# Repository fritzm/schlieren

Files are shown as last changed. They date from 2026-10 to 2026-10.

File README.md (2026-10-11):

# iPhone schlieren

A portable, single-mirror schlieren apparatus that images with an iPhone and packs into a checked suitcase. It
is built for a vacation week at Deep Creek and afterward will serve as a bench-top lab instrument.

An LED lights a source slit. A spherical mirror a few meters away re-images the slit back at the optical head.
Air density gradients near the mirror bend the returning light past a cutoff (knife edge, wire, or color
filter), and an iPhone behind a telephoto lens records the resulting contrast. The optical head is a pair of
2020-extrusion rails attached to a plywood pivot plate, and is designed to rest on a tabletop or bench.
Thorlabs SM1 optomechanics hold the LEDs, condenser, the slit, and the cutoff, and printed PLA parts handle
everything that doesn't need metal precision. The mirror sits in its own tripod-mounted cell.

## Repository layout

| Path | Contents |
|---|---|
| [`docs/design/`](docs/design/) | Baseline design, as numbered Markdown fragments, one per subsystem. Start with `01-context-and-layout.md`; open areas are flagged **Provisional** and rolled up in `11-open-work.md`. |
| [`docs/schlieren-design.pdf`](docs/schlieren-design.pdf) | The whole design document rendered as one PDF, generated from the fragments. |
| [`bom/bom.csv`](bom/bom.csv) | BOM: one row per allocation, with vendor, SKU, quantity, and procurement or CAD state. |
| [`bom/schlieren-bom.xlsx`](bom/schlieren-bom.xlsx) | The BOM as a workbook with a summary tab, generated from the CSV. |
| [`src/schlieren/parts/`](src/schlieren/parts/) | build123d models of custom parts and part assemblies. Each module's docstring gives its frame and scope. |
| [`src/schlieren/cli/`](src/schlieren/cli/) | Utility scripts for building and viewing parts and generating documents. |
| [`tests/`](tests/) | Checks on dimensions, clearances, interference, optical calculations, and BOM consistency. |
| [`cad/vendor/`](cad/vendor/) | Unmodified manufacturer STEP models of purchased parts. |
| [`docs/reference/`](docs/reference/) | Manufacturer drawings and datasheets. |

This git repository is the source of truth for both the design and the BOM. The PDF and the workbook are
generated views: to change them, edit the fragments or the CSV and rebuild.

## Tooling

- [uv](https://docs.astral.sh/uv/) for management of Python environment and dependencies.
- [build123d](https://build123d.readthedocs.io/) for declarative, parametric geometry, including models for
  3d-printed parts. The Python source is authoritative, and STEP/STL exports are derived files.
- [OCP CAD Viewer](https://github.com/bernhard-42/vscode-ocp-cad-viewer) VS Code extension to display
  assemblies in-editor (`--show`).
- [VTK](https://vtk.org/) for offscreen shaded renders of parts, used as design-document figures (`--figure`).
- [ruff](https://docs.astral.sh/ruff/) for lint and formatting.

## Quick start

```sh
uv sync                                          # set up the environment
uv run run-tests [--full]                        # run the tests in parallel (--full adds the slow ones)
uvx ruff check . && uvx ruff format .            # lint and format

uv run light-source [--show] [--figure]          # light source focus stack-up
uv run slit-head [--show]                        # source-slit flexure head
uv run carriage [--show]                         # cutoff carriage
uv run cassette [--show]                         # cassette blank and clamp bars
uv run rail-shoe [--show] [--figure]             # common rail shoe

uv run build-design-doc [--pdf]                  # docs/design/ -> exports/docs/, docs/schlieren-design.pdf
uv run build-bom-xlsx                            # bom/bom.csv -> bom/schlieren-bom.xlsx
uv run reconcile-bom [workbook.xlsx] [--apply]   # edits made in a workbook -> bom/bom.csv
```

Every part command takes `--help`. The part commands write their STEP/STL files to `exports/`. `--figure`
re-renders the part's design-document figure in `docs/design/figures/`.

Once a design element is accepted, it is propagated to the CAD source and tests, the relevant `docs/design/`
fragment, and `bom/bom.csv`. All of these must agree. In Claude Code, the `/finalize-decision` skill does
this.

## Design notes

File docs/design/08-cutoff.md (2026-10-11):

## 8. Cutoff

The cutoff sits at the returned slit-image plane on the imaging rail. It is a rotating carriage
([§8.1](#81-spigot-and-rotation-interface)–[8.5](#85-spring-seating-and-retraction)) holding interchangeable
64 mm cassettes ([§8.6](#86-common-cassette-standard)–[8.7](#87-cassette-clamp-bars)), which carry the cutoff
element: a knife edge, a fine wire ([§8.8](#88-fine-wire)), or a color filter
([§8.9](#89-color-filter-material)). The carriage model is `src/schlieren/parts/carriage.py`; the cassette
blank and clamp bars are modeled in `src/schlieren/parts/cassette.py`.

<p align="center">
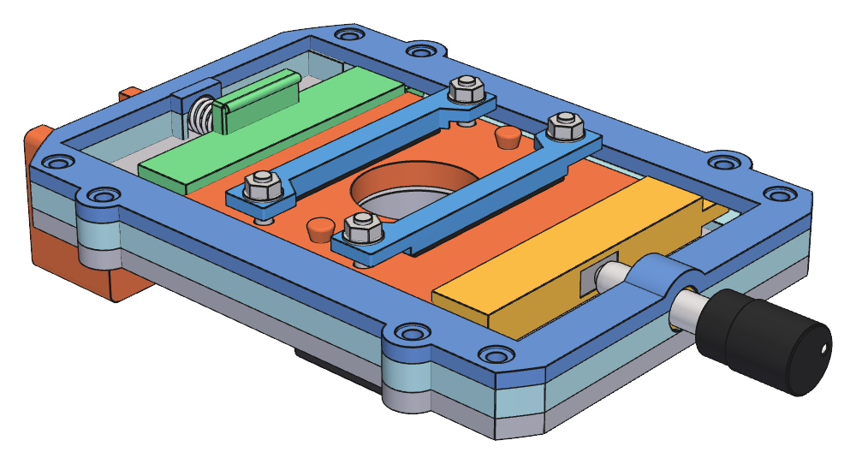
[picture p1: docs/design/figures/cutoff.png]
Cutoff carriage from the mirror side with a cassette seated: base plate, guide frame, keeper plate, driven and spring plungers, FAS100 adjuster, and cassette with clamp bars
  
  <br>
  <em>Fig. 8. Cutoff carriage with a seated cassette: guide frame, keeper plate, driven and spring plungers, and the FAS100 fine adjuster</em>
</p>

### 8.1 Spigot and rotation interface

The carriage mounts in 1 × Thorlabs SM1RC/M through a hollow printed spigot integral with the carriage base
plate, the same interface as the slit-head adapter
([§7.6](07-source-slit.md#76-rotation-mount-and-clearances)):

- Ø30.48 mm spigot (SM1 tube OD nominal), clamped directly by the SM1RC/M split ring (Ø30.7 mm bore, 10.16
  mm thick, M4 locking screw across the split); the spigot end is flush with the ring's rear face;
- Ø24 mm light bore through the spigot, matching the plate aperture;
- Ø34 mm shoulder as the ring's axial stop: the ring seats against it, which places the plate back 12.0 mm in
  front of the ring face. Do not clamp the ring away from the shoulder.

The 12.0 mm ring gap is set by the rail shoe, not the post. At nominal zero the plate reaches about 63.5 mm
below the optical axis, past the shoe top (about 52.4 mm below), so the plate back must clear the shoe end
(15 mm from the post axis): calculated clearance 2.1 mm to the shoe and 10.7 mm to the post body, at every
rotation. The shoulder clears the post top by 5.1 mm.

No SM1 tube, printed split clamp, retaining ring, or printed SM1 thread is used. The
SM1RC/M provides the rotational bearing and lock: when loosened, the carriage rotates on its spigot. Nothing
retains the spigot axially while the ring is loose, so support the carriage when rotating it.

Required carriage rotation:

- at least ±90°
- preferably ±100–120°

Define nominal zero as:

- cutoff line horizontal;
- fine-adjust translation vertical;
- fine adjuster pointing upward.

The cassette-loading side of the carriage faces the mirror, so cassettes are loaded and retracted from the
forward side, away from the telephoto. The spigot, slip ring, and post are therefore aft of the base plate; the
ring's rear face, 22.2 mm behind the plate back, is the rearmost part of the station on the optical axis and
is what the telephoto front must clear.

Fore/aft optical positioning is done by moving the rail shoe.

Rotation envelope: the 2020 rail runs beneath the carriage at every rail position, 72.35 mm below the axis.
The base plate, guide frame, and keeper are trimmed to a 70.35 mm radius about the optical axis (the rail top
less 2 mm clearance). Only the outer plate corners are removed; the plate is otherwise 86 mm wide, widened to
94 mm at the side keeper-screw lugs ([§8.4](#84-cassette-seating)). Calculated from the CAD, the carriage with
its FAS100 rotates clear of the rail over ±150°; only the FAS100 knob reaches the rail, near ±170–180°.
Nothing projects below the plate at nominal zero ([§8.5](#85-spring-seating-and-retraction)). **Provisional:**
clearance to other equipment on the rail near the cutoff station is not yet checked.

### 8.2 Spigot print and fit

The carriage base plate is printed deck down with the spigot up, so the spigot and shoulder need no
supports; the guide frame above the deck is a separate print (the base/frame split exists for this). The three
datum-pin shanks ([§8.4](#84-cassette-seating)) lie outside the shoulder and are flush-cut on the plate back.

**Provisional:** the spigot is printed at the SM1 tube nominal; fit-test it in the SM1RC/M and adjust if
needed.

### 8.3 Fine adjustment

The carriage uses:

- 1 × Thorlabs FAS100, 1/4 in-80 × 1.00 in
- 1 × McMaster 98625A950 brass 1/4 in-80 insert
- 1 × McMaster 2006N292 compression spring

Insert geometry is taken exactly from the McMaster-Carr 98625A950 drawing, not from a generic 1/4 in-80 insert
model. The drawing gives: internal
thread 1/4 in-80; body outside diameter 0.313 in (7.950 mm); overall axial length 0.313 in (7.950 mm);
under-flange/body length 0.298 in (7.569 mm); flange outside diameter 0.352 in (8.941 mm); flange thickness
0.010 in (0.254 mm); specified drill-bit size 0.313 in (7.950 mm); and minimum material thickness 0.298 in
(7.569 mm). The 0.352 in dimension is the flange OD, not the bore or insert-body OD.

The insert bore is nominally 0.313 in (7.950 mm), matching the drawing. The printed bore is a pilot, finished
after printing with a 5/16 in (0.3125 in) drill rather than relying on FDM accuracy; on the slit head this
gave a good press fit ([§7.7](07-source-slit.md#77-fabrication-and-fit)). The 8.5 mm insert support exceeds
the drawing's 0.298 in (7.569 mm) minimum material thickness, with about 3 mm of radial PLA around the insert
body. The spring plunger loads the FAS100 tip, so the screw pushes the insert outboard, toward the knob. The
flange is therefore on the inner (cassette-side) face of the adjuster block, in a flush counterbore 0.2 mm
larger in diameter than the flange, with the body running outboard: the reaction bears the flange against the
block instead of relying on the press fit. The insert is pressed in from the cassette side before the plungers
are installed, with the flange bottoming in its pocket.

FAS100 / insert travel envelope for CAD: the FAS100 uses a 1.000 in (25.4 mm) long 1/4 in-80 adjuster screw.
The 80 TPI pitch gives 0.0125 in (0.3175 mm) axial motion per revolution. Using the insert's 0.313 in overall
axial envelope as a conservative full-engagement allowance leaves approximately 0.687 in (17.45 mm) of
theoretical screw motion. That is a geometric clearance estimate, not a published FAS100 travel
specification. The carriage's working translation is ±5 mm / 10 mm total, leaving useful adjuster margin
before either end stop.

The FAS100 ball tip does not bear directly on printed PLA. The driven plunger carries a small hard bearing
insert made from a nickel-plated rectangular NdFeB magnet:

- Amazon B0DMCY4FN1
- N52 Bar Magnet - 10 mm L × 5 mm W × 2 mm H
- one magnet in the driven plunger

The magnet is used as a hard, wear-resistant plated bearing surface; its magnetic function is incidental. It
sits in a close-fitting printed pocket with its rear face fully supported by PLA, with a small CA or epoxy
tack for retention. The FAS100 ball contacts the broad plated face rather than bare PLA.

### 8.4 Cassette seating

Cassette motion is controlled by opposed plungers:

- fine adjuster on one side;
- spring-loaded plunger opposite;
- three fixed rear datum contacts on the carriage define the cassette optical plane;
- shallow cassette/plunger bevels generate axial seating force against the datum contacts.

The three rear datum contacts are McMaster 97936A109 brass escutcheon pins / decorative finishing nails, used
head-first as small domed sliding contacts. Each pin is approximately 3/8 in long, with a 0.050 in (1.27 mm)
smooth shank and 1/8 in (3.18 mm) domed head.

Mount each pin through a through-hole in the printed carriage with the domed brass head on the cassette side.
The holes are modeled Ø1.75 mm: the measured 0.050 in (1.27 mm) shank, plus the 0.38 mm diametral hole
undersize measured on the first base-plate print (the Ø24 mm aperture printed 0.930 in), plus 0.1 mm fit
clearance. If a shank binds, finish the hole with a #54 (0.055 in) drill. The hole fit only locates the shank; the head sets the datum. Seat the underside of the head firmly against the carriage datum face so datum height is
established mechanically rather than by adhesive thickness. Wick a small amount of CA around the shank from
the back for retention, then flush-cut and dress the projecting shank at the back of the carriage. Keep CA out
from beneath the head/contact surface.

The three pin heads form a broad triangular support pattern around the optical aperture. The cassette rear
face is the sliding datum surface and provides unobstructed swept tracks over the three domed
contacts throughout the fine-adjust travel. The pin coordinates, set in the carriage CAD, keep every datum
contact out of the swept track of the cassette's rear M3 clamp-screw countersinks over the full travel, so
the datum tracks stay on uninterrupted printed rear-face material at every cassette position.

The plunger bodies are constrained to the intended translation axis by ears/tabs riding in slotted guiding
rails. The guide slots prevent unwanted lateral movement or rotation while permitting the required axial
plunger travel.

The plungers need an assembly path into their guides: both longitudinal ends of the guide path are occupied,
by the FAS100 adjuster support on one side and the spring end wall on the other. The guide tracks are
therefore open from the cassette-loading side; the plungers drop into them, and a separate printed keeper
frame closes only the guide-ear regions.

The keeper is a perimeter frame, not a solid lid: the central upper aperture must remain open for cassette
insertion and removal. Its side members span the plunger guide tracks and retain the guide ears against upward
escape while the printed track walls carry the lateral guidance loads. The frame may be locally scalloped or
notched where the FAS100 adjuster axis intersects its envelope, provided the material directly over the swept
guide-ear paths and the load paths to the fasteners remain intact. The keeper's spring-end member also carries
the roof of the end-wall spring cup ([§8.5](#85-spring-seating-and-retraction)).

Keeper retention is mechanical, with eight fasteners per carriage. Each is the existing common McMaster
91292A114 M3 × 0.5 × 12 mm socket-head screw with a McMaster 91828A211 full-height M3 × 0.5 hex nut (5.5 mm
across flats × 2.4 mm high), captive in a hex pocket opening from the plate back. Screw heads and nuts bear
directly on the PLA, without washers; tighten only to a light snug, since the joint needs little clamp and a
firm hex-key torque can crush the bearing face.

- Four end screws, at (±38.5, −53) and (±38.5, +52) mm in the carriage frame (y along the travel, +y toward
  the FAS100). Each sits on solid fill closing its guide track from 1 mm beyond the outermost ear position
  to the plate end. The fill is also the plungers' end stop: 1 mm past full loading retraction for the spring
  plunger and past +5 mm travel for the driven plunger. These positions keep each nut pocket at least 1 mm
  inside the rotation envelope ([§8.1](#81-spigot-and-rotation-interface)).
- Four side screws, at (±42, ±37) mm, beside the middle of each plunger's ear travel. Each sits in a Ø10 mm
  round lug that widens the base, frame, and keeper locally to 94 mm, clipped at the guide-track wall.

The side screws carry the ear wedge reactions (below) into the frame close to where they arise. A first-order
beam estimate, with each keeper side member simply supported between adjacent screws, gives at most about
0.07 mm of upward keeper deflection at the ears at the maximum-compression load (with a PLA modulus of
about 3000 MPa assumed). That is within the 0.25 mm free play between the ears and the keeper; with only the
four end screws it would be about 1.5–2 mm. The keeper
side members are 3.0 mm thick. **Provisional:** if a print shows too much lift, a keeper with 5.0 mm side
members fits the same screws: its counterbores are deeper, so the head seat height is unchanged.

The screw heads sit in an approximately 0.5 mm-deep recess in the keeper, and the captive hex pockets are
approximately 2.5 mm deep. This leaves approximately 1.5 mm of PLA above each nut pocket and gives nearly
full use of the 12 mm screw length, with only slight nominal screw projection beyond the nut. The keeper seats on broad
printed lands, so the fasteners clamp it against the carriage rather than suspending it between isolated
points.

The vertical guide stack is: 4.0 mm carriage back plate; 2.0 mm rise from the plate front to the lower
guide-ear running surface; 3.0 mm plunger guide ears in a 3.4 mm guide channel; and a 3.0 mm keeper frame.

**Provisional:** the guide-stack dimensions, keeper recess and nut-pocket depths, sliding fits, and datum-pin
projection are first-print values, to be tuned from printed fit.

Use a very light film of plastic-safe lubricant on the PLA-on-PLA sliding interfaces, particularly the plunger
ears/tabs in their guide slots and any other plunger sliding faces. The lubricant is McMaster 1418K51
clear silicone grease, NLGI 1. Smooth/dress the printed sliding surfaces first, apply only a trace amount,
cycle the mechanism, and wipe away visible excess so the lubricant acts as a thin boundary film rather than a
grease-packed slide. Keep lubricant away from CA/epoxy/RTV bonding surfaces and apply it only after nearby
adhesive work is complete.

The plunger seating lips and the cassette edge bevels are 27.5° from the cassette plane, with a 1.25 mm
bevel depth.

For keeper-frame sizing, McMaster lists the 2006N292 spring rate as 0.14 lbf/mm. At the 9 mm fiducial
compression this corresponds to approximately 5.6 N of in-plane plunger force; at the 14 mm most-compressed
end of normal travel it is approximately 8.7 N. A frictionless first-order wedge model at 25–30° from the
cassette plane gives approximately 9.7–12.0 N upward reaction per plunger at fiducial and approximately
15.1–18.7 N per plunger at maximum normal compression. These reactions are carried upward through the plunger
ears into the keeper frame; about 20 N per plunger is the working-load scale before safety margin.

**Provisional:** the bevel angle and depth, and the seating-force estimate (which neglects sliding friction),
are pending a cassette insertion, seating, and tilt trial.

### 8.5 Spring seating and retraction

The spring plunger is preloaded by the McMaster 2006N292 compression spring ([§8.3](#83-fine-adjustment)),
acting between the frame's spring end wall and the plunger's outboard face on an axis 7.5 mm above the plate
back. No guide rod, retract handle, or penetration of the end wall is used; a guide rod through the end wall
would project below the axis past the rail top at nominal zero.

Each spring end sits in a printed cup, 3 mm deep, sized to the measured 0.272 in (6.91 mm) coil OD plus 1.0
mm diametral clearance:

- one cup extends inboard from the end wall: its side walls are on the guide frame, and its roof is carried
  by the keeper's spring-end member, so the keeper closes over the spring end when installed;
- one cup extends outboard from the spring plunger;
- both cups are open toward the plate deck, which carries the coil. Their side walls and roofs locate the
  coil ends laterally and against escape toward the cassette-loading side. Both print with legs on the bed
  and the roof bridging the coil, without supports.

The spring's free length is about 4–4.6 times its mean coil diameter, and both ends sit on parallel faces
because the plunger is guided. That is below the roughly 5.3 critical ratio for buckling with fixed ends,
so the cups need only locate the ends rather than guide the full length. The spring itself does not guide
the plunger; the slotted carriage guides constrain plunger translation and rotation.

The spring has a free length of approximately 25.5 mm. The carriage is designed around a 16.5 mm
spring length at the fiducial / mid-travel cassette position, corresponding to approximately 9 mm spring
compression from free length.

Normal supported plunger travel is ±5 mm about the fiducial position, for 10 mm total working travel. The
corresponding spring-length range is approximately:

- 21.5 mm at the least-compressed end of normal travel;
- 16.5 mm at fiducial / mid travel;
- 11.5 mm at the most-compressed end of normal travel.

Loading retraction is a further 6 mm from fiducial (10.5 mm spring length), leaving 4.5 mm between the cups.
Any additional compression capacity is treated as design margin rather than normal commanded travel.
**Provisional:** the solid height of the 2006N292 spring is not verified, so the loading retraction is checked
against the printed cups but not against the spring's own limit.

Retraction for cassette loading uses a thumb tab on the spring plunger's front face at its outboard end:

- 20 mm wide × 3 mm thick × 6 mm tall, centered between the guide ears and outside the cassette footprint;
- the thumb reaches over the cassette and pushes the tab's inner face outboard, at about 9 N at full
  retraction;
- 0.5 mm chamfers on the exposed edges; the spring-facing face is left square;
- a Ø1.6 mm grip bead along the inner top edge, flush with the tab top, prevents finger slip.

The tab is kept low, close to the plane of the guide ears, so that pushing on it does not twist the plunger
and jam the ears.

### 8.6 Common cassette standard

Cassette envelope:

- 64 × 64 × 5 mm PLA
- 24 mm diameter central clear aperture
- identical shallow bevels on all four perimeter edges
- insertable at 0 / 90 / 180 / 270°
- perimeter kept clear enough to use any opposing edge pair
- orientation/polarity indicated by markings rather than a mechanical key.

Cassettes load with the spring plunger retracted 6 mm beyond fiducial
([§8.5](#85-spring-seating-and-retraction)).

Cassette variants, all built on the common blank:

1. single razor knife edge;
2. centered fine-wire or filament dark-field cutoff ([§8.8](#88-fine-wire));
3. striated / multicolor gel filter ([§8.9](#89-color-filter-material));
4. dark-center color filter ([§8.9](#89-color-filter-material)).

<p align="center">
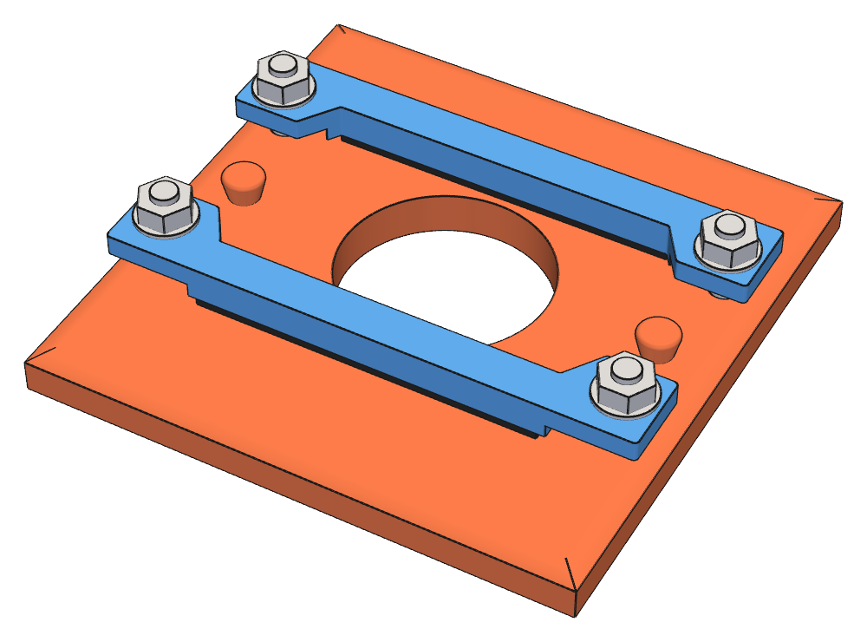
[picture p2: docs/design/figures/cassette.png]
Assembled cassette: 64 mm base with 24 mm aperture, two clamp bars with screws, washers and nuts
  
  <br>
  <em>Fig. 9. Cassette blank with its two clamp bars and hardware</em>
</p>

The standard cassette blank carries one opposed pair of integral filament cleats on the front / non-datum
face, rather than making cleats a special cassette variant: two cleats, one on each side of the 24 mm optical
aperture, at (±25, 0) mm on an aperture centerline, outboard of the razor blades and clamp bars. The cleats
are slightly conical, Ø3.5 mm at the cassette face widening to Ø5 mm toward the top and rising 3 mm, so
filament tension drives fine wire or thread down against the cassette front face. The tops are rounded to
avoid damaging fine wire.
Route a filament in an S path, around opposite sides of the two cleats; the free span then crosses
approximately through the aperture centerline. Small angular error from finite cleat diameter or wrapping is
acceptable because the SM1RC/M rotates the complete tube/cassette assembly. This makes the same universal
cassette blank usable for blade, filter, Photofoil, wire, and thread experiments while keeping the rear datum
face unobstructed.

**Provisional:** cleat geometry is pending a wire-mounting trial.

### 8.7 Cassette clamp bars

These bars and their hardware are the clamping standard for the cassettes
([§8.6](#86-common-cassette-standard)); the slit head uses its own smaller bars
([§7.5](07-source-slit.md#75-blade-clamping)).

Common clamp bars:

- two identical printed rigid PLA bars fit each cassette;
- each bar uses two fasteners, one toward each end, so clamp force is distributed along the element;
- no holes are made through razor blades, filter material, or other optical elements;
- no blade-specific locating pocket or guide is required;
- McMaster 9852N37 adhesive-backed 1/32 in, 60A solid EPDM is applied to the removable clamp-bar face to
  provide compliance and friction;
- the bar bears primarily on the broad flat portion of a razor blade rather than relying on the folded
  spine for its clamp datum;
- the same clamp-bar geometry holds razor knife edges, Roscolux gel/filter material, Photofoil,
  and similar thin sheet cutoff elements.

Clamp-bar fastening is from the cassette rear/datum face toward the optical/front face so no screw ends or
nuts can protrude from the sliding/datum surface. Fasteners are positioned outside the optical-element
footprint where practical; the clamp bar spans and pinches the element against the cassette front face. At
each fastener, use:

flush M3 countersunk flat-head screw → 5 mm cassette body → printed clamp bar → M3 flat washer → ordinary M3
hex nut

The M3 flat-head screw is seated fully flush or very slightly below the rear cassette face and retained in its
countersink with a small CA tack using McMaster 1818A45 / Loctite 4061. The CA serves only to keep the screw
captive and resist rotation while the front-side nut is adjusted; it is not relied upon as the structural
clamp load path. The ordinary M3 nut remains exposed and accessible on the front of the clamp bar. Place the
washer between the nut and printed bar. Do not use prevailing-torque/nyloc nuts or threadlocker here.

#### Cassette clamp-bar hardware

| Component | McMaster part | Specification |
|---|---|---|
| Flat-head screw | [92125A133](https://www.mcmaster.com/92125A133/) | M3 × 0.5 × 14 mm, fully threaded 18-8 stainless, 90° countersunk head; 6 mm head diameter, 1.7 mm head height, 2 mm hex drive |
| Flat washer | [93475A210](https://www.mcmaster.com/93475A210/) | 18-8 stainless, 3.2 mm ID × 7 mm OD × 0.4–0.6 mm thick; DIN 125 / ISO 7089 |
| Ordinary full-height hex nut | [91828A211](https://www.mcmaster.com/91828A211/) | M3 × 0.5, 18-8 stainless, 5.5 mm across flats × 2.4 mm high; DIN 934 (the common split-clamp nut, [§5.3](05-post-support.md#53-common-rail-shoe)) |

The clamp bars are 4 mm printed PLA. The cassette blank has four Ø3.4 mm screw holes at (±27, ±12) mm with
rear-entry 90° countersinks matched to the 92125A133 head (Ø6.2 mm at the face: 6 mm head plus 0.2 mm
diametral allowance), and each bar end provides a washer bearing land at least 7.2 mm across. The screw head
finishes flush with or slightly below the rear/datum face so it cannot contact the carriage datum pins or
interfere with cassette sliding. The fasteners, bars, nuts, cleats, and projecting screw ends are clear of the
24 mm optical aperture and carriage interfaces. The holes and countersinks are features of the universal
cassette blank, not blade-specific geometry.

Because the clamp fasteners do not pass through the optical element, the screw length is not sized from a
blade-thickness stack. The 14 mm length gives full nut engagement and holds razor blades under the 4 mm bars,
with the head seated flush in its countersink. The screws are vertical and the lips act at the cassette edges,
so the screw length does not bear on the lips; the bar ends, which reach the bevel zone, are relieved to clear
them.

### 8.8 Fine wire

The dark-field filament set is enameled copper magnet wire in three readily available AWG sizes. The
nominal diameters below are bare-conductor diameters; enamel makes the finished optical obstruction slightly
larger.

| Wire size | Nominal bare diameter | Approx. metric diameter | Experimental role |
|---|---|---|---|
| 44 AWG magnet wire | 0.0020 in | 0.0508 mm | fine / high-sensitivity filament |
| 34 AWG magnet wire | 0.0063 in | 0.160 mm | intermediate filament, near the expected slit-image width  |
| 30 AWG magnet wire | 0.0100 in | 0.255 mm | coarse filament for stronger gradients / deeper dark field |

Exact finished outside diameter is not critical for the qualitative instrument.

The universal cassette cleat pair described in [§8.6](#86-common-cassette-standard)
is the quick-change mounting for these wires and for dark sewing thread or other fibers. Apply only
modest tension, particularly to 44 AWG wire; the conical cleats seat the filament against the cassette face,
and the S-wrap places the free span approximately on the aperture centerline.

### 8.9 Color-filter material

Filter material is cut from the Roscolux 3 × 6 in Designer Color Selector, which provides more useful
material per color than very small swatches.

For color schlieren:

- use the white Nichia LED;
- lock camera white balance;
- lock exposure.

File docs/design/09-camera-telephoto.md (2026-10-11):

## 9. Camera and telephoto support

The camera and lens are chosen ([§9.1](#91-camera)–[9.2](#92-telephoto)). Their support is a lens cradle and
a phone rest ([§9.4](#94-support-concept)–[9.8](#98-retaining-bands)), with an alignment procedure
([§9.9](#99-lens-alignment)). **Provisional:** the phone rest's retainer and safety catch, the fit allowances
of the printed yokes and of the rod groove, which are still to be tested, and the alignment procedure
([§11](11-open-work.md#11-provisional-areas-and-next-steps)).

### 9.1 Camera

- Apple iPhone 17, base model, in intended protective case
- held in landscape, with the rear cameras toward the mirror and the camera end of the phone toward the
  optical axis
- the Main camera is used, at 1× (or its 2× crop). It is the lower of the two rear apertures with the phone
  in portrait, "rear camera 2" on Apple's drawing (`docs/reference/Apple-iPhone-17.pdf`); the upper aperture
  is the Ultra Wide, used only at 0.5×
- measured camera optical axis approximately 60.6 mm above the lower long edge, in the case
- measured Main camera axis approximately 1.350 in / 34.3 mm from the near short edge, in the case; the case
  shape makes this hard to measure accurately with calipers
- measured case thickness approximately 0.510 in / 12.95 mm (bare phone 7.95 mm); the case corners are rounded
- measured mass 188.7 g bare, with its glass screen protector, and 238.6 g in the case

Manufacturer dimensions of the bare phone, from the drawing:

- both rear cameras are 13.62 mm from the nearer long edge, on a line parallel to it, so the measured axis
  height applies to either aperture
- the Main camera is 31.34 mm from the top short edge, 17.72 mm beyond the Ultra Wide at 13.62 mm
- body 149.61 × 71.45 × 7.95 mm; the camera glass stands 3.45 mm above the back glass

The drawing and the two measurements agree. The cameras are 57.83 mm from the farther long edge of the bare
phone, so the measured 60.6 mm implies a case wall of about 2.8 mm at that edge; the 31.34 mm and the measured
34.3 mm imply about 3.0 mm at the short edge (both calculated).

Initial recording modes:

- 4K/30 for normal work;
- 4K/60 for faster flow phenomena;
- SDR / HDR off as a stable starting point.

### 9.2 Telephoto

- iOgrapher proSnap 7×
- 17 mm mount
- approximately 37.0 mm diameter
- approximately 116.8 mm long
- measured mass approximately 215 g

Measured barrel sections, from the aft end forward:

| Section | Length | Outside diameter |
|---|---|---|
| aft end | 0.565 in / 14.4 mm  | not measured |
| rear cylindrical barrel | 1.300 in / 33.0 mm  | 1.457 in / 37.01 mm |
| long cylindrical barrel | 2.25 in / 57.2 mm | 1.459 in / 37.06 mm |
| focus ring | 0.455 in / 11.6 mm  | not measured |
| front lip | 0.175 in / 4.4 mm | not measured |

Both cylindrical sections are suitable for clamping, giving about 90 mm of clampable barrel from 14.4 mm to
104.5 mm from the aft end. The focus ring must stay clear. The measured sections sum to 4.745 in / 120.5 mm,
about 3.7 mm more than the overall length listed above; the difference is not resolved.

The lens barrel, rather than the phone shell, is the preferred transverse optical datum because accurate lens
centering minimizes vignetting.

### 9.3 Alignment requirements

The returned slit image at the cutoff is the aperture stop for the camera: every ray from the test region
passes through it, then spreads again at the ±1.82° cone angle
([§3.2](01-context-and-layout.md#32-source-cone)). The values below are calculated, and are **provisional**
where they rest on assumed values: a lens front about 42 mm behind the cutoff plane, a 10 mm lit slit image, a
Main-camera pupil of about 3.7 mm (6 mm focal length at f/1.6), and a telephoto clear aperture near 30 mm.

| Quantity | Value |
|---|---|
| Beam cone at the lens front | about 2.7 mm diameter |
| Beam footprint at the lens front | about 2.7 × 12.7 mm |
| Slit image at the phone, reduced 7× by the lens | about 1.4 mm long |
| Frame at 1×, 4K 16:9, through the lens | about 9.9° × 6.1° |
| Mirror in the frame | 3.6° of the 6.1° height  |

The resulting tolerances on the camera and lens as one body:

- centering on the beam: about ±8 mm along the slit direction and ±13 mm across it, before the reduced slit
  image leaves the phone pupil; the lens front aperture allows a similar margin;
- pitch: about ±1.2°, the spare frame height either side of the mirror;
- yaw: about ±3°.

Pointing is therefore the governing adjustment, and centering is forgiving. Image quality still favors
centering well inside the vignetting limit.

### 9.4 Support concept

The phone and the lens threaded onto its case are one rigid body. The lens barrel is its datum
([§9.2](#92-telephoto)): the lens is held at two stations along its barrel, and the phone hangs from its lens
mount. Two separate rail fixtures carry them:

- the lens cradle, specific to the lens, holds the barrel at both stations on four adjusting screws
  ([§9.5](#95-lens-cradle)) and is held down by two retaining bands ([§9.8](#98-retaining-bands));
- the phone rest, specific to the phone, supports the phone's lower edge at one point
  ([§9.6](#96-phone-rest)). A different phone needs only this part redesigned.

<p align="center">
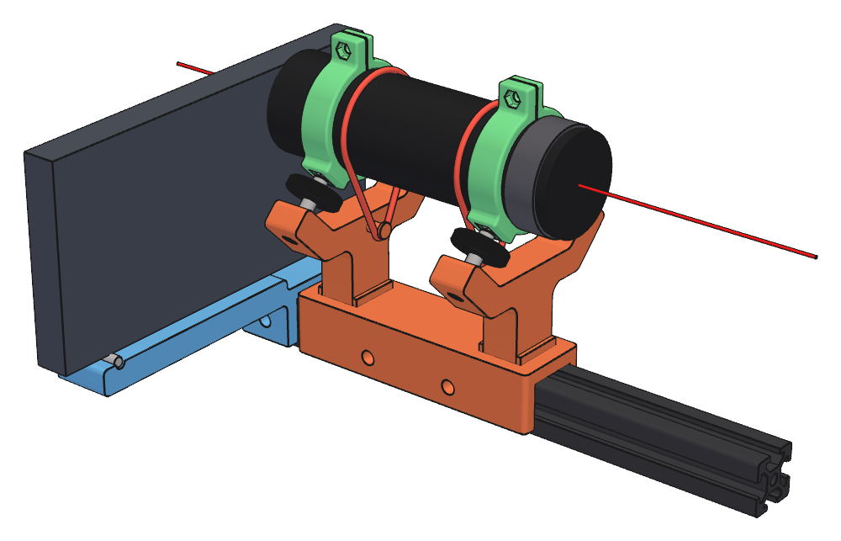
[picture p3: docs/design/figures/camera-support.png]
Lens cradle and phone rest on the imaging rail: two collars on the lens barrel, each on a pair of inclined screws in a yoke bolted to the cradle shoe, a retaining band round the barrel beside each yoke, and the phone hanging from the lens with its lower edge on the rest arm
  
  <br>
  <em>Fig. 10. Lens cradle and phone rest on the imaging rail, with phone and lens envelopes</em>
</p>

The body is located by six contacts and no more, so adjusting one station does not strain the lens mount:

- four screw tips, two at each station, fix the lens axis in x and z at both stations, and so its position,
  pitch, and yaw;
- one of those tips sits in a groove, fixing the lens fore/aft;
- the phone rest fixes roll.

Each station's pair of screws places one point of the lens axis, so the two stations give position and
pointing without coupling between them beyond the lever ratio. A second groove would fix the fore/aft position
a second time against the spacing of the collars on the lens, and would stop the pad sliding that yaw
adjustment needs. Holding the lens, not the phone, takes the lens weight off the lens mount: the mount carries
about 1.3 N in shear (calculated), against roughly 170 N·mm of bending if the lens were cantilevered from
the phone.

The model is `src/schlieren/parts/camera_support.py`. It holds the printed parts, with their fits, pockets,
fillets, and wall thicknesses, and checks contacts, clearances, and the lens and cord loads; the lens, phone,
and purchased hardware are envelopes or vendor models.

### 9.5 Lens cradle

The cradle is five printed parts and two bands. Two split collars clamp the barrel; two yokes carry the
adjusting screws; one shoe straddles the rail and carries both yokes.

#### Collars

Each collar is a thin ring on the barrel with a clamp ear on top and a flat pad platform at each screw:

- the aft collar on the rear cylindrical section, centered about 24 mm from the lens aft end, which leaves
  finger room for its thumb nuts ahead of the phone; the fore collar on the long cylindrical section, centered
  about 96.5 mm from the aft end, with its front face about 2 mm behind the focus ring; about 72.5 mm between
  them;
- 12 mm wide, with a 3 mm wall round a bore of 37.3 mm, the measured 37.0 mm barrel plus a 0.3 mm diametral
  allowance, so a collar is 43.3 mm across. The wall is thin because the pad platforms carry the local
  thickness; the pad loads are a few newtons, so stiffness is not limiting;
- the ear takes the common M3 split-clamp hardware ([§5.3](05-post-support.md#53-common-rail-shoe)) with the
  rail shoe's split and ear thicknesses: the screw passes through the thin ear on the left, and the hex nut is
  captured in a pocket in the thicker ear on the right, open to the outside, with a roof of at least 1.5 mm
  over it. The screw axis stands 4.25 mm above the ring top, so the screw head clears the ear's root fillet;
- inside corners, the ear and pad platform roots, are filleted at 2 mm for stress control; the other outside
  corners and the outer edges of both ring ends at 1 mm, for the fingers. The faces of the split stay sharp so
  that the gap stays fixed.

The two collars are the same part except that the aft collar's left pad is a rod seat in place of a magnet seat
(below).

#### Pads and pockets

Each screw tip bears on a flat pad on the collar, tangent to the ring at the screw: the pad face stands one
magnet thickness outside the ring, and the pocket floor is tangent to the ring's outside. Each pad sits in a
pocket with a rim round it, so a ball end that wanders reaches a wall instead of the edge of the pad:

- three pads are the 10 × 5 × 2 mm magnets, set with the 10 mm side across the rail, bonded into pockets
  0.2 mm larger across each dimension (0.1 mm per side, the allowance every printed magnet pocket in the
  design uses);
- the fourth, at the aft left screw, is a groove between two dowel pins of 3 mm diameter and 10 mm length,
  lying across the rail on the pocket floor. The ball sits between them, free to slide across the rail but not
  along it;
- the rim stands 0.8 mm above the pad face. The ball-tip screw's end face is 1.2 mm behind the ball apex, so
  the rim stays below it;
- above the pad face the pocket opens outward by 0.23 mm per side, so that the rim edge stops the ball apex
  1 mm short of the pad edge, the margin the travel limits below assume. The walls round the pockets are
  1.5 mm.

The two screws of a station are at right angles, so advancing one slides the collar across the other's pad by
the same distance. Pad size, not screw travel, limits the adjustment. Calculated, keeping each ball 1 mm
inside the pad edges, which the rim enforces:

| Adjustment | Range |
|---|---|
| Each screw | about ±3 mm |
| A station, in x or in z alone | about ±4 mm |
| Lens tilt, pitch or yaw | about ±2° |
| One turn of both screws of a station | about 1.1 mm, or about 0.9° |

The tilt limit comes from the 5 mm side of the pads, on the pads that slide along the rail as the lens yaws
about the groove. These ranges cover the alignment tolerances ([§9.3](#93-alignment-requirements)) and the
expected build errors.

#### Yokes

Each yoke is one printed part, 14 mm thick along the rail, in the shape of a T with an inclined arm either
side, printed on its side so that every layer lies in the plane of the loads:

- a column 20 mm wide, the width of the rail, rising from the shoe to a crossbar 10 mm thick whose top stands
  13 mm below the bottom of the collar, clear of the thumb nuts;
- each arm is a slab 10.5 mm thick, square to its screw. Its lens-side face carries the insert and runs down
  to the crossbar top; its back face runs down to the crossbar underside, so there is no stub or step;
- fillets of 5 mm at the column root, 4 mm where the arm blends into the crossbar, and 2 mm round the outer
  arm corners;
- each arm holds a heat-set insert ([§9.7](#97-adjuster-hardware)) in a 6.4 mm hole from the lens-side face
  with the flange recessed flush. The wall round each insert and its flange recess is at least 2.9 mm, and a
  5.5 mm bore carries on through the back of the arm for the screw and its hex key.

Under the adjuster reactions of about 8 N the crossbar root sees about 0.6 MPa and the arm tip moves about
0.01 mm (calculated, with a PLA modulus of about 3000 MPa assumed), so stiffness and strength are not
limiting; the fillets are margin.

#### Shoe and joint

The shoe's lower section is that of the common rail shoe ([§5.3](05-post-support.md#53-common-rail-shoe)): a
20.4 mm rail opening, 5 mm side walls, 18 mm skirts, a 5 mm deck, and 2 mm rounded outside corners. M5
clearance holes cross the skirts at rail mid-height for the side-slot screws, two of them 36 mm apart midway
between the collars. The shoe extends 9 mm beyond each collar face, so it is symmetric about the middle of the
two stations. Each yoke is bolted to the deck, so that it prints on its side and the shoe prints without
supports:

- one 90° countersunk M5 screw from the underside of the deck, on the rail centerline, with its head flush
  with the underside, into a heat-set insert in the column foot, with the insert's flange bearing on the deck;
- two straight walls on the deck across the rail, ahead of and behind the column, 1.6 mm thick and 3 mm high,
  with 0.2 mm clearance to the column faces. They locate the yoke along the rail and stop it twisting;
- the screw ends inside the insert with about 5 mm of engagement.

The collar bore, clamp-ear hardware pocket, and magnet pockets are fit-tested on printed collars, and the
shoe's rail opening, screw holes, and seat on the rail on a printed shoe.
**Provisional:** the groove between the rods and the ball-stop rims, and the insert holes and locating walls of
the yokes, are untested; the magnet and rod adhesive is not chosen; the fitting and removal sequence is
set by the bands ([§9.8](#98-retaining-bands)).

### 9.6 Phone rest

The phone hangs from the lens with its body to the outboard side of the optical axis
([§3.4](01-context-and-layout.md#34-common-optical-axis-datum)). Its weight, centered about 43 mm from the
lens axis, would turn the lens in its collars. The phone rest stops that: the phone's lower long edge sits on
one dowel pin lying along the rail, about 100 mm outboard of the axis, on the arm of a short printed
shoe of its own. The shoe's lower section is that of the cradle shoe ([§9.5](#95-lens-cradle)), with a
single pair of M5 clearance holes for the side-slot screw.

- The shoe is 22 mm long and centered under the rod. The arm runs across the rail from the shoe's outboard
  wall to 8 mm beyond the rod, 10 mm deep and as long as the shoe. The rod lies half sunk in a half-round seat
  in its top, with 0.1 mm radial clearance, and is bonded.
- The part is printed on its side, like the yokes: it is one profile in the plane of the load, extruded along
  the rail, so every layer is that profile and the arm needs no bridge or support. Only the side-slot screw
  bores are horizontal. The shoe's vertical corners on the arm side are left sharp, where the arm joins the
  wall.
- The arm's inside corners are filleted against stress: 3 mm under the arm where it meets the shoe wall, the
  largest because it takes the bending, and 2 mm where the arm top steps up from the deck. The outside corners
  at the tip and the step are rounded 2 mm, and the seat edges 0.5 mm. The arm is kept 10 mm deep so that the
  root fillet stays at least 1 mm above the side-slot screw head on the outside of the skirt.

- With the measured 60.6 mm camera-axis height, the phone's lower edge is about 11.75 mm above the rail top.
- The rest carries about 1.0 N (calculated, same assumptions as the contact loads in
  [§9.8](#98-retaining-bands)). It matters to the cradle, because it keeps the fore pad load from falling
  toward zero.
- The rest is fixed. Raising or lowering the aft collar rolls the phone slightly about the lens axis, which
  does not matter; the phone is not gripped and slides on the rod.
- The rest holds no optical alignment, so its dimensions are not critical.
- Because the rod lies along the rail, the rest needs to be only roughly under the phone.

**Provisional:** a light retainer to keep the phone on the rod, and a loose safety catch against a knock, are
not yet designed.

### 9.7 Adjuster hardware

There are four adjusting screws, two under each collar. Each is a ball-tip set screw in a heat-set insert in
its yoke arm, with a thumb nut threadlocked mid-screw as a handwheel.

Hardware:

- McMaster 93339A252, M5 × 0.8 × 25 mm ball-tip set screws: alloy steel, 25.0 mm overall including the ball,
  2.5 mm hex socket, and a 3.0 mm ball (ball size from the vendor model, `cad/vendor/McMaster-93339A252.step`;
  drawing `docs/reference/McMaster-93339A252.gif`)
- McMaster 94459A797, M5 flanged heat-set inserts: 6.73 mm long overall, with a 7.92 mm flange 1.02 mm thick,
  a 7.11 mm knurled body, and a 6.32 mm pilot (drawing `docs/reference/McMaster-94459A797.gif`; vendor model
  `cad/vendor/McMaster-94459A797.step`). The drawing calls for a 6.40 mm hole and at least 6.48 mm of
  material. Each is set from the lens-side face of its arm, flange outward and recessed, so the screw's
  reaction presses it into its hole. Two more are set in the yoke feet for the joint screws
- McMaster 92125A208, M5 × 0.8 × 10 mm 18-8 stainless hex-drive flat head screws (90°, 10 mm head), two for
  the yoke joints ([§9.5](#95-lens-cradle))
- McMaster 92815A202, M5 thumb nuts used as threadlocked mid-screw handwheels
- Loctite 271, McMaster 91458A160
- heat-set installation tip 92160A327;
- Amazon B0DMCY4FN1, N52 Bar Magnet - 10 mm L × 5 mm W × 2 mm H, as hard plated bearing pads, one at each of
  three screws;
- McMaster 91585A351, Ø3 × 10 mm 18-8 stainless dowel pins (ISO 2338 m6, chamfered ends), two for the groove
- at the fourth screw;
- McMaster 91585A457, Ø4 × 20 mm 18-8 stainless dowel pin, for the phone rest rod;
- the common M3 split-clamp screw and nut ([§5.3](05-post-support.md#53-common-rail-shoe)), one pair per
  collar.

### 9.8 Retaining bands

The collars sit on their pads under gravity alone, so each pad pair is held down by an elastic band. The pairs
carry only the lens and phone weight, and the fore pair least of all: contact loads, calculated from the
measured 215 g lens and 238.6 g cased phone, with an assumed balance point 60–70 mm from the aft end, are

- aft screw pair: about 2.7–3.0 N;
- fore screw pair: about 0.5–0.8 N. The phone hangs behind the aft collar, so its weight pivots the lens about
  the aft screws and unloads the fore pair, but it cannot lift it: the lens moment is the larger.

A downward push on the phone, such as a screen tap, lifts the fore end when it exceeds roughly 2.5 times the
fore pair's load, about 1.2–1.9 N unaided, and a sideways nudge unseats a pad when it exceeds the load on its
pair. The alloy-steel screw tips are attracted to the magnet pads, which adds some preload; it is not relied
upon until measured.

Each band is an endless O-ring, 2 mm in section, of oil-resistant 70A Buna-N with an inside diameter of about
40 mm, lying round the bare barrel beside its yoke on the side toward the other collar, 11.8 mm from the
collar's center. Its two legs run down inboard of the thumb nuts to a peg on the center of the yoke's
crossbar face. The peg has a 4 mm stem and a 6 mm lip; the ring lies on the stem under the lip.

- The band acts on the barrel, which the collar's clamp carries to the pads, exactly as it carries the lens
  weight. The ring needs no groove on the collar and settles into the plane through the peg.
- The legs are about 65° above horizontal, so 5 N of hold-down takes about 2.75 N in each leg. A ring of that
  size stretched about 19% pulls about 3 N (calculated, with a 70A rubber modulus of about 5 MPa assumed).
- Each band acts about 12 mm from its collar. With one band beside each yoke, between the collars, each pad
  pair receives the hold-down of 5 N in total from the two bands (calculated), about 4.2 N from its own band
  and about 0.8 N from the other. That raises the tap threshold at the fore end to roughly 13–14 N.
- The legs clear the thumb nuts by more than 5 mm, so the cord stays out of the way of the fingers.
- To fit, slide the rings over the focus ring onto the bare barrel before clamping the collars on; refitting
  one afterwards means stretching it round the other collar and its ear. A band stays on the lens when the
  lens is lifted out with the peg end unhooked.

**Provisional:** the contact loads rest on the assumed balance point above, and the ring size
is chosen on an assumed modulus; the next larger inside diameter is the alternative if the 40 mm ring is too
tight.

### 9.9 Lens alignment

This is the alignment the cradle must make possible, kept here as a feasibility check on the adjusters; a
consolidated setup and alignment procedure comes later. **Provisional:** the procedure is untested, and its
targets assume that the printed shoe seats fully on the rail top and the collars seat on their barrel sections.

The tolerances ([§9.3](#93-alignment-requirements)) are loose compared with the adjuster resolution, so the
alignment is mechanical first and then finished through the camera, with no laser.

Each adjuster moves the lens axis along its own screw, so at one station, with the screws at ±45° and a thread
pitch of 0.8 mm (calculated):

- both screws turned the same way, n turns: z moves n × 1.13 mm;
- the two turned in opposite directions, n turns each: x moves n × 1.13 mm;
- one screw alone, one turn: x and z each move about 0.57 mm;
- pitch and yaw come from setting the two stations 72.5 mm apart differently; 1 mm of difference is about
  0.8°.

The sequence:

1. Fit both collars and the phone on the lens at their stations, set the four thumb nuts to equal exposed screw
   length (mid-travel), and note their positions. Put the cradle shoe on the rail with its clamp screws loose.
2. Slide the shoe along the rail to put the lens front at the planned gap from the slip ring's rear face, then
   snug the clamp screws. The groove at the aft left screw fixes the lens fore/aft on the cradle, so nothing
   later moves it.
3. Center the barrel at each collar mechanically, aft first, and re-measure the other collar after each
   change. Height: from the shoe deck, beside the yoke, up to the barrel top, whose target is 72.35 + 18.5 − 5
   = about 85.85 mm (the deck top is 5 mm above the rail top; the barrel diameters of 37.01 and 37.06 mm
   differ by too little to matter). Lateral: with the shoe pressed to one side of the rail, taking up its 0.4
   mm lateral play, from the shoe's outer wall to the barrel side, whose target is 18.5 − 15.2 = about 3.3 mm.
   A ±0.5 mm error between the stations is about 0.4° of pitch or yaw, within tolerance.
4. Finish through the camera, because the phone camera may not lie on the barrel axis in its mount and case.
   With the source lit and the cutoff cleared, view the returned field at 1× and trim the aft screws in x and z
   until the vignetting at the corners is even; a turn of one screw is only about 0.6 mm, so turn in small
   steps. The mirror should sit centered in the frame, which sets pitch and yaw to within the spare 1.2°.
5. Check the roll: the phone rest rod should just touch the phone's lower edge without lifting it, a paper
   strip sliding between them with light drag. A lower-edge height different from the model is taken up by
   shimming the rod seat.
6. Record the final thumb nut positions, so that refitting the lens needs only a check.

- Each station's range is only about ±4 mm, so a larger offset is taken up by moving the shoe on the rail, not
  with the screws.
- The aft thumb nuts must stay clear of the phone while they are turned; the model leaves finger room, to be
  checked on the real phone.

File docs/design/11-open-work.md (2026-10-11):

## 11. Provisional areas and next steps

Procurement state and the CAD state of printed parts are tracked in `bom/bom.csv`.

### 11.1 Provisional areas

Design areas marked **Provisional** in the sections above:

- **Light source** ([§6.2](06-light-source.md#62-led-modules), [§6.3](06-light-source.md#63-common-heatsink),
  [§6.7](06-light-source.md#67-focus-and-module-interchange)): M3 heatsink-screw length; lead hole size
  against the lead insulation, cap thread root radius, and Convoy star notch geometry
  ([§6.4](06-light-source.md#64-led-board-mounting)); heatsink temperature rise at 700 mA; white-module
  long-gap focus margin.
- **Cutoff carriage** ([§8](08-cutoff.md#8-cutoff)): spigot fit in the SM1RC/M; guide-stack, recess, and
  pocket dimensions, sliding fits, and datum-pin projection; keeper lift under the ear wedge reactions; bevel
  angle and seating force; the spring's solid height against the loading retraction; clearance to other equipment near the cutoff station.
- **Cassettes** ([§8.6](08-cutoff.md#86-common-cassette-standard),
  [§8.7](08-cutoff.md#87-cassette-clamp-bars)): filament-cleat geometry.
- **Lens cradle and phone rest** ([§9](09-camera-telephoto.md#9-camera-and-telephoto-support)): fit
  allowances of the rod groove, ball-stop rims, and yokes (including the locating walls on the shoe), the
  magnet and rod adhesive, and the retaining-band ring size on an assumed modulus
  ([§9.5](09-camera-telephoto.md#95-lens-cradle), [§9.8](09-camera-telephoto.md#98-retaining-bands)); the
  phone rest's retainer and safety catch ([§9.6](09-camera-telephoto.md#96-phone-rest)); the lens alignment
  procedure, untested ([§9.9](09-camera-telephoto.md#99-lens-alignment)). The alignment tolerances rest on
  assumed lens and camera values, and the contact loads on an assumed lens balance point and phone mass.
- **Printed PLA** ([§1.1](01-context-and-layout.md#11-fabrication-envelope)): creep and relaxation of sustained
  loads, notably the slit-head width-stage preload ([§7.7](07-source-slit.md#77-fabrication-and-fit)), and
  heat exposure of printed parts in transport and use.
- **Mirror cell** ([§10.5](10-mirror-cell.md#105-mirror-mounting),
  [§10.8](10-mirror-cell.md#108-mirror-safety-and-transport-retention)): RTV adhesion primer decision; safety
  retainers; transport sandwich covers, foam, and 1/4-80 thumb screws; quick-release screw hole sizes
  ([§10.9](10-mirror-cell.md#109-tripod-interface)).

### 11.2 Next steps

1. Fit-test the printed cutoff carriage and a cassette blank ([§8](08-cutoff.md#8-cutoff)), including
   datum-pin seating, bevel seating, and keeper lift. Trial wire mounting on the
   filament cleats ([§8.6](08-cutoff.md#86-common-cassette-standard)).
2. Fabricate both threaded LED modules: drill and tap the caps and heatsinks, center each board, and set focus
   on the slit blades; measure the cap thread root radius, and check the lead hole size and the Convoy star
   notch geometry against the physical parts ([§6.4](06-light-source.md#64-led-board-mounting)). Confirm that
   the white module reaches focus; if not, add a thin cap-flange shim
   ([§6.7](06-light-source.md#67-focus-and-module-interchange)). Bench-test the heatsink temperature rise.
3. Fit-test the printed yokes on the shoe, the rod groove, and the retaining bands
   ([§9](09-camera-telephoto.md#9-camera-and-telephoto-support)), after measuring the magnet pull on a screw
   tip, the lens balance point, and the cased phone mass; design the phone rest's retainer and safety catch;
   test the lens alignment procedure ([§9.9](09-camera-telephoto.md#99-lens-alignment)).
4. Design the mirror-cell safety retainers and settle the transport sandwich
   ([§10.8](10-mirror-cell.md#108-mirror-safety-and-transport-retention)), and confirm the quick-release screw
   hole sizes ([§10.9](10-mirror-cell.md#109-tripod-interface)).
5. Assemble the tabletop optical head.
6. Perform a dry optical layout near 3.2 m before making any remaining irreversible holes or bonds.
7. Bond the mirror into the moving plate ([§10.5](10-mirror-cell.md#105-mirror-mounting))
   after a dry fit and an adhesion test.

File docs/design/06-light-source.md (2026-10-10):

## 6. Light source

The light source is a single assembly on one TR50/M post and common rail shoe
([§5](05-post-support.md#5-common-rail-mounted-post-support)): a Thorlabs SMR1/M holder that carries one of
two interchangeable threaded LED modules on its rear face and a condensing lens and iris on its forward face.
The condenser images the LED emitter onto the source slit ([§7](07-source-slit.md#7-source-slit)), and the
iris sets the angular size of the illumination cone ([§3.2](01-context-and-layout.md#32-source-cone)).

### 6.1 Assembly and stack order

Parts:

- threaded LED module, green or white ([§6.2](#62-led-modules))
- Thorlabs SMR1/M fixed threaded holder
- Thorlabs SM1V05 adjustable lens cell
- Thorlabs ACL2520U-A condenser
- Thorlabs SM1L03 tube
- Thorlabs SM1D12 adjustable iris
- Thorlabs SM1CP1 internally threaded protective cap
- Thorlabs SM1EC2 protective cap
- TR50/M post + common rail shoe

From the LED to the slit:

1. threaded LED module, its SM1CP2M cap threaded into the LED-side face of the SMR1/M;
2. SMR1/M on the TR50/M (0.400 in / 10.16 mm thick, SM1 thread through, no lip; 0.870 in / 22.10 mm
   post-top-to-axis offset);
3. SM1V05, its externally threaded sleeve entering the slit-side face of the SMR1/M and locked with the
   included SM1NT. The ACL2520U-A sits in the SM1V05 body with its plano face on the internal seat (toward
   the LED) and its convex face toward the open end;
4. SM1L03, threaded into the SM1V05 open end;
5. SM1D12, threaded into the SM1L03.

<p align="center">
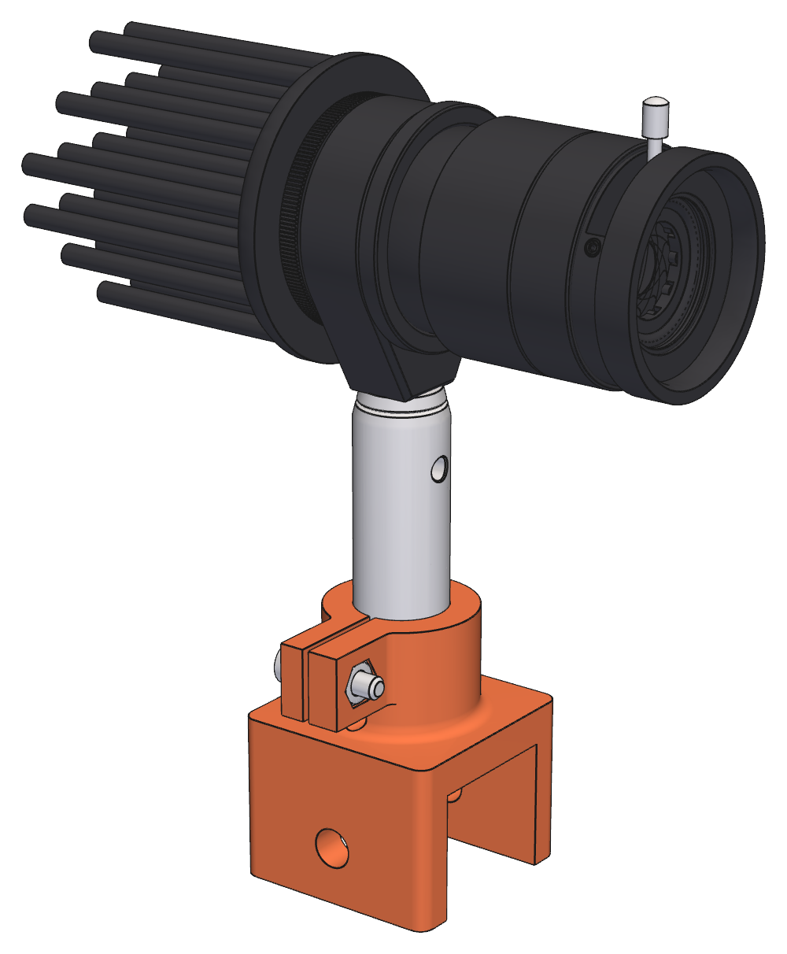
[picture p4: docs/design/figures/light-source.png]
Light source on its TR50/M post and rail shoe: pin-fin heatsink and LED cap behind the SMR1/M, with the SM1V05, SM1L03, and iris ahead of it
  
  <br>
  <em>Fig. 4. Light source on its post and rail shoe: heatsink and LED module, SMR1/M, SM1V05, SM1L03, and iris</em>
</p>

<p align="center">
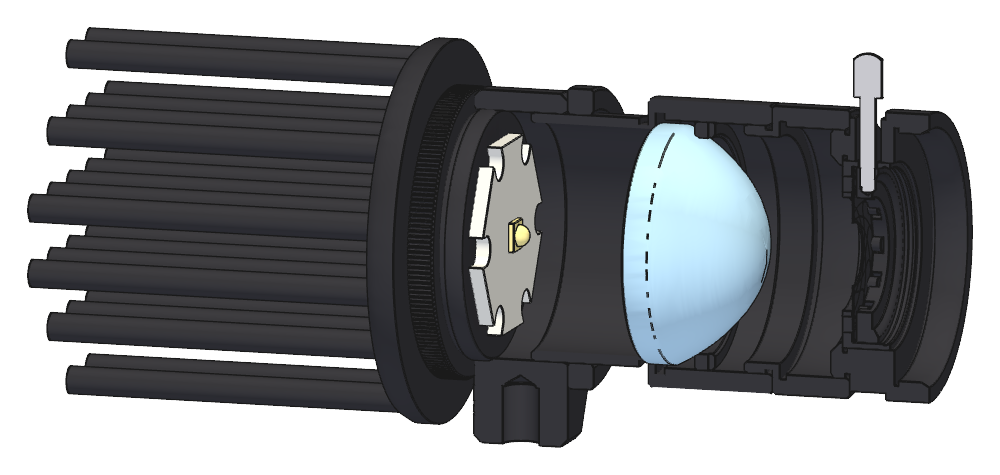
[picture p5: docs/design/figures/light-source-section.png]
Light source with the SMR1/M, SM1V05, SM1L03, and iris cut along the optical axis, and the heatsink, cap, star board with LED, and condenser lens shown whole
  
  <br>
  <em>Fig. 5. Light source cutaway, showing internal position of LED module and condensing lens</em>
</p>

The ACL2520U-A convex vertex sits about 0.7 mm inside the SM1V05 open end, so the SM1L03 spacer is required
ahead of the iris; the SM1D12 interferes with the lens if threaded directly into the SM1V05.

The cap and the SM1V05 sleeve share the SMR1/M thread. The cap threads in until its knurled flange seats on
the SMR1/M face, so the LED position is fixed and the SM1V05 engagement is the focus adjustment
([§6.7](#67-focus-and-module-interchange)). Engagement runs from the Thorlabs minimum of 0.110 in / 2.79 mm to
about 5.7–5.8 mm, where the sleeve end comes within 0.3 mm of the LED board. Turning the SM1V05 moves the
lens, SM1L03, and iris together relative to the LED; the resulting few-millimeter iris shift is negligible
against the 150 mm iris-to-slit spacing.

Thorlabs SM1 part dimensions in this stack-up (SMR1/M, SM1CP2M, SM1V05) are the exact inch-primary values from
the vendor STEP models in `cad/vendor/`, not the rounded millimeter values on the drawings. The TR50/M is
metric-primary and keeps its 50 mm / Ø12.7 mm nominals (its STEP model is rounded to inches).
`src/schlieren/parts/light_source.py` encodes the stack-up; `uv run light-source` prints the focus ranges.

### 6.2 LED modules

There are two interchangeable LED modules, each a self-contained threaded assembly. Each LED board mounts on
an identical threaded SM1 carrier so that the SM1 thread and cap flange, rather than the individual MCPCB
pattern, are the interchange standard.

| | Green module | White module |
|---|---|---|
| Emitter | OSRAM OSLON SSL 120, 530 nm nominal | Nichia 519A R9080, 5000 K |
| Board | NewEnergy star board, LST1-01F06-GRN1-00 | Convoy 20 mm star/DTP carrier |
| Initial operating current | approximately 350 mA | approximately 500–700 mA |

Module stack, from the rear toward the condenser:

1. Alpha CN40-40B heatsink ([§6.3](#63-common-heatsink)), bolted to the rear face of the cap with thermal
   compound between;
2. Thorlabs SM1CP2M externally SM1-threaded end cap (0.210 in / 5.33 mm solid aluminum, 0.100 in / 2.54 mm
   thread, Ø1.200 in / 30.48 mm knurled flange);
3. LED star board on the front face of the cap ([§6.4](#64-led-board-mounting)).

Interfaces:

- The cap flange is the repeatable axial stop on the SMR1/M face; the module's rotational position at the
  stop does not matter.
- The SM1 thread centers the emitter on the condenser axis; no vertical calibration is required.
- Heatsink fastening: three M3 × 6 mm socket-head screws (**provisional** length) through the CN40 base, their
  heads in open cells between four pins, into M3 holes tapped through the cap. Positions are in
  [§6.4](#64-led-board-mounting).
- Leads drop past the star board's flat edges through two Ø2.0 mm holes in the cap and the heatsink base, 11.0
  mm from the axis (inside the thread root), and out between the pin columns. **Provisional:** the hole size
  against the lead insulation ([§6.4](#64-led-board-mounting)).
- Fabrication is drilling and tapping of purchased aluminum parts only. Every hole in the cap and the heatsink
  base is a through hole, so plain plug taps are enough.

Clearances:

- The heatsink's lowest point is 2.1 mm above the TR50/M post top at any rotation (22.10 mm axis offset minus
  20 mm maximum radius).
- The heatsink front face is 2.79 mm (0.110 in) behind the SMR1/M face (the cap flange thickness).
- The SMR1/M thread bore leaves about 3 mm of radial room around a 20 mm board for leads.

### 6.3 Common heatsink

- Alpha CN40-40B natural-convection pin-fin heatsink, one per module
- Ø40.0 mm (+0/−0.5) × 40 mm overall, 3.0 mm flat base, Ø2.8 mm pins on a 6.9 mm square grid
- 6063 aluminum, black anodized; 24.6 g
- manufacturer natural-convection rating 6.9 °C/W

At about 2 W (white module at 700 mA) the expected rise is roughly 14 °C above ambient; the green module
dissipates about 1.1 W. The rating is the manufacturer's pins-up test; the module runs with pins horizontal,
which pin fins tolerate well. **Provisional:** bench-test the temperature rise at 700 mA before relying on
it.

The heatsink is round so that it clears the post at every rotation while the module is threaded in
([§6.2](#62-led-modules)); a larger or non-round heatsink would sweep its corners below the post top during
threading.

### 6.4 LED board mounting

Measured star-board thicknesses (calipers):

- green NewEnergy star: 0.0625 in / 1.59 mm (the datasheet lists 0.047 or 0.067 in; the measured value governs)
- white Convoy 20 mm star: 0.0590 in / 1.50 mm

Both boards are about 20 mm across (NewEnergy 0.783 in / 19.9 mm, catalog).

Fastening standard:

- M2 × 0.4
- McMaster 92095A452, M2 × 5 mm screws
- tapped directly into the front (threaded) face of the SM1CP2M cap, in through holes
- 1.6 mm tap drill, drilled through
- M2 × 0.4 HSS plug tap; a through hole needs no bottoming tap

The 5 mm screws are shorter than the 5.33 mm cap, so they stop short of the heatsink face.

Use the cap's center-drill mark as the layout datum for the board hole pattern. Transfer each carrier board's
hole geometry from the physical board rather than assuming it from the other module. Slightly oversized board
holes permit final centering of the emitter on the cap axis: a 0.3 mm emitter offset moves the slit image
about 2 mm, so center each board by watching its image on the slit blades before final tightening.

Add thin insulating washers beneath screw heads where necessary to keep the metal screw heads away from
exposed board contacts:

- McMaster 91545A410
- M2 lubricant-filled nylon flat washer

A thin layer of thermal compound is used between board and cap.

#### Cap and heatsink hole layout

All holes in the cap and in the heatsink base are **through holes**, drilled from one face. Plain plug taps
(M3 × 0.5, M2 × 0.4) cut full threads through them; no bottoming tap is required. No screw reaches the far
face of the cap: the M2 screws are 5 mm under the head and the M3 screws engage about 3 mm past the 3.0 mm
heatsink base.

<p align="center">
  Plan view from the LED side of the cap, the 20 mm star board, and the heatsink pins, with the M3, M2, and lead holes and their positions
  <br>
  <em>Fig. 6. Cap and heatsink hole layout, seen from the LED side, in the frame of the heatsink pin lattice</em>
</p>

Coordinates are in millimeters from the optical axis, +x to the right and +y up as seen from the LED side, in
the frame of the pin lattice; the cap and the heatsink are drilled to the same coordinates:

| Hole | Position | In the cap | In the heatsink base |
|---|---|---|---|
| M3, three | (+6.90, +6.90), (−6.90, +6.90), (+6.90, −6.90) | Ø2.5 tap drill, M3 × 0.5 | Ø3.3 clearance |
| M2, two | (±9.525, 0) | Ø1.6 tap drill, M2 × 0.4 | none |
| Lead, two | (0, ±11.0) | Ø2.0 | Ø2.0 |

- M3 holes: each is the center of a cell of the pin lattice, 4.88 mm from each of four pins, so the Ø5.5 mm
  socket head lands between the pins with 0.73 mm to spare and the key reaches it. Three screws hold the
  heatsink without a rocking axis; the fourth cell is free but unused. Roughly 70% of each hole's area lies under the star, a small loss of its
  thermal contact.
- M2 holes: in the two opposite corner notches of the star on the x axis (the 0.375 in notch center radius). They are covered by the solid heatsink base, so they do not meet the
  pins.
- Lead holes: on the axis through the midpoints of two opposite flat edges of the star, tangent to each edge
  at 11.0 mm radius. Each is 1.1 mm from the nearest pins, in the 4.1 mm channel between pin columns.
- The smallest wall between holes in the cap, measured to the thread major radius, is 4.9 mm. The lead holes'
  outer edges, at 12.0 mm radius, leave about 0.5 mm to the estimated thread root.

**Provisional:** the lead hole size against the insulation of the leads (a Ø2.0 hole leaves no room for
thicker wire, since the outer edge is limited by the thread root); the cap thread root radius (estimated at
12.5 mm, to be measured on a cap); and the Convoy star's notch geometry, which is taken from the NewEnergy
drawing and must be checked against the physical board.

Full-scale drilling templates for both parts, to print at 100% and stick on, come from
`uv run light-source --templates`: the cap template goes on the LED-side face with its crosshair on the
center-drill mark, and the heatsink template on the flat base face, aligned to the pin rows. Both are viewed
from the LED side, so they share one set of coordinates.

### 6.5 Power and wiring

Power supply:

- ALIENTEK DP100
- use DC constant-current operation rather than PWM to avoid rolling-shutter banding

Connector standard:

- Micro-Fit 3.0
- 2-pin
- 18 AWG factory pigtails

Connector hardware:

- 2 × Molex 214758-1021, male-to-pigtail, 150 mm — module side
- 1 × Molex 214756-1023, female-to-pigtail, 600 mm — supply side
- 1 × Pomona 1825-02 red/black 4 mm banana-plug pair

The supply side should present recessed/socket contacts.

### 6.6 Condenser optics

The condenser images the LED emitter onto the source slit (about 6.6× magnification). Each slit point then
sees the iris uniformly filled at the LED radiance, which gives a uniformly illuminated mirror. The LED image
should cover the illuminated slit length; the domes enlarge the apparent emitters by about 1.4–1.5×.

Defocus in either direction underfills the ±1.8° cone: iris-edge rays then trace back beyond the emitter
edge, darkening the mirror edge and shortening the uniformly lit slit length. With the LED at the condenser
focus (12 mm, collimated) the emitter cannot fill the cone even at the slit center.

Using ACL2520U-A catalog values (EFL 20.1 mm, BFL 12.0 mm; object-side principal plane about 8.1 mm inside
the plano face) and about 153 mm from the convex vertex to the slit, the optimum emitter-to-plano-face gap is
about 15 mm. The optimum moves only about ±0.7 mm for ±30 mm of slit position.

### 6.7 Focus and module interchange

Setup values (not hard CAD dimensions):

- emitter-to-plano-face gap approximately 15 mm, measured to the emitting surface, not the dome top
- useful gap range roughly 13–17 mm
- condenser/iris-to-slit spacing approximately 150 mm
- initial iris opening approximately 9–10.5 mm (about ±1.7–2.0° at 150 mm)

Set focus by imaging the LED onto the closed slit blades and turning the SM1V05 until the emitter image is
sharp and centered, then lock the SM1NT and open the slit.

Calculated emitter heights above the cap face, using the measured board thicknesses, about 0.07 mm of solder,
and the apparent emitter heights through the LED domes (calculated from the manufacturer outline drawings:
OSLON about 0.45 mm, 519A about 0.75 mm), with the gap range each module reaches over the SM1V05 engagement
range:

| Module | Emitter height above cap face | Emitter-to-plano gap range | SM1V05 engagement at 15 mm gap |
|---|---|---|---|
| Green | about 2.1 mm | about 13.2–16.2 mm | about 3.9 mm |
| White | about 2.3 mm | about 12.9–16.0 mm | about 3.7 mm |

The two modules focus about 0.2 mm apart in engagement, about one-third of a turn of the SM1 thread. An
index mark per module on the SM1V05 is optional.

Focus margin about the 15.04 mm optimum gap is about 1.1 mm (long-gap side) and 1.8 mm (short-gap side) for
the green module, and only about 0.93 mm and 2.1 mm for the white module. The white module's long-gap travel
is limited by the SM1V05 minimum engagement. **Provisional:** the white module's reduced margin is to be
confirmed on the build. If it cannot reach a sharp slit image, space its cap flange off the SMR1/M face with
a thin shim (about 0.1 mm restores 1.0 mm of margin). The shim moves the whole module away from the lens and
keeps the flange as the axial stop; a shim under the star board would instead shorten the gap and make the
shortfall worse.

Module interchange:

1. disconnect the Micro-Fit lead;
2. unscrew the module (cap and heatsink together) from the SMR1/M, about four turns;
3. screw in the alternate module until its flange seats;
4. touch up focus on the closed slit blades if needed.

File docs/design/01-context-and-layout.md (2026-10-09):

# Portable Single-Mirror Schlieren Apparatus

**Design Description**

Revision: Oct 4, 2026

This document describes the design of the apparatus, and is maintained authoritatively as Markdown fragments
in the project repo on github at <https://github.com/fritzm/schlieren/tree/main/docs/design>.

## Conventions

- The design described here is the baseline. Unless marked otherwise, dimensions, parts, and methods are
  settled.
- **Provisional** marks a design area, dimension, or method that is still open or evolving, typically pending
  a physical fit check, measurement, or further design. Provisional areas are rolled up with next steps in
  [§11](11-open-work.md#11-provisional-areas-and-next-steps).
- Measured values, manufacturer specifications, and calculated values are identified as such where the
  distinction matters; a measured value takes precedence over a catalog value.
- Quantities, vendors, part numbers beyond those needed to define the design, procurement state, and the CAD
  state of printed parts are recorded in the BOM (`bom/bom.csv`), not here.

## 1. Project context and design constraints

The apparatus is a portable, single-mirror schlieren system intended initially for several days of
vacation/travel use in a location with a large room and a substantial tabletop. It should remain useful
afterward as a bench-top laboratory instrument.

The complete system should pack into a standard airline rolling suitcase. Plan around the ordinary 50 lb / 23
kg checked-bag target.

The design is cost-conscious rather than constrained to a fixed dollar ceiling. Commodity 2020 extrusion,
Baltic birch plywood, standard fasteners, and printed PLA are preferred where they are adequate. Commercial
optomechanics are used where they materially simplify alignment or provide precision that would otherwise be
troublesome.

### 1.1 Fabrication envelope

Near-term 3D printing is PLA only. Critical optical heights and precision datums should be
established by metal posts, optical hardware, shim stock, mechanical stops, or adjustment mechanisms rather
than relying solely on as-printed PLA dimensions.

PLA softens at about 55–60 °C and creeps under sustained load, so printed parts must not see direct sun or a
closed vehicle, and sustained loads on them are kept low: clamp screws are tightened to a light snug, and the
preloaded flexures of the slit head are checked for relaxation ([§7.7](07-source-slit.md#77-fabrication-and-fit)).
The LED heatsinks rise only about 14 °C above ambient ([§6.3](06-light-source.md#63-common-heatsink)).

The following are out of scope:

- custom machined parts requiring a mill or lathe;
- cutting stainless-steel stock or sheet to custom shape or length.

Use off-the-shelf metal parts, vendor-supplied finished dimensions, plywood, aluminum that can be
drilled/tapped with ordinary shop tools, thin foil, or printed PLA. Simple drilling and tapping of the
aluminum LED carrier caps and heatsinks is within scope.

A table saw, drill press, and small hand router are available and are expected to be used for accurate working
of Baltic birch plywood panels (thanks, Bret!)

## 2. System overview and physical layout

The apparatus consists of two main physical assemblies:

1. a tabletop optical head; and
2. a separate mirror cell, normally tripod-mounted approximately 3.2 m away.

The tabletop optical head uses two independently yaw-adjustable 2020 aluminum-extrusion rails mounted to a
common Baltic-birch front pivot plate. The rails diverge slightly away from the mirror-facing end so that each
rail follows one optical chief ray:

- the source rail carries the illumination system directed toward the mirror;
- the imaging rail carries the cutoff and camera system for the return beam.

The source rail contains, in optical order:

1. light source (interchangeable threaded LED/heatsink modules, condenser, and adjustable iris)
2. source-slit flexure head

The slit is the effective optical source. The LED primarily illuminates that slit through the condenser and
therefore does not itself require the same precision vertical positioning as the slit.

The imaging rail contains:

1. cutoff carriage at the returned slit-image plane;
2. lens cradle, which supports and aligns the telephoto lens;
3. phone rest, under the iPhone hanging from the lens.

The spherical mirror forms an image of the source slit back near the optical head. Refractive-index gradients
in the test region near the mirror deflect portions of this return beam relative to the cutoff, producing
schlieren contrast.

Several source-side and imaging-side fixtures deliberately share common mechanics. Three locations use a
common Thorlabs TR50/M optical post + printed rail shoe concept:

1. light source;
2. source-slit;
3. cutoff.

The source slit and the cutoff both rotate about the optical axis on printed fixtures mounted in Thorlabs
SM1RC/M SM1 slip rings. The slit uses a flexure head with fine centering and slit-width adjustment
([§7](07-source-slit.md#7-source-slit)); the cutoff uses a carriage that accepts interchangeable cassettes,
allowing knife-edge, wire, and color-filter experiments without changing the supporting mechanism
([§8](08-cutoff.md#8-cutoff)).

The mirror cell uses a three-point, approximately 120°-spaced fine-adjustment architecture with compression
springs and spherical washer interfaces ([§10](10-mirror-cell.md#10-mirror-cell)). The mirror is compliantly
supported in the moving plate by six radial silicone pads, which are cast and cured in place between the
mirror edge and the inner surface of the plywood aperture.

## 3. System-level geometry

### 3.1 Primary optic

- Mirror: Skyoptikst D203F1600
- Diameter: 203 mm
- Focal length: 1600 mm
- Surface: spherical
- Radius of curvature / nominal operating distance: approximately 3200 mm

The source slit and imaging/cutoff system operate near the mirror center of curvature. The test region is near
the mirror, where outgoing and returning beams remain close together.

The source slit is the effective optical source. The spherical mirror re-images the slit near the optical
head; the returned slit image defines the cutoff plane.

### 3.2 Source cone

At 3200 mm, the mirror subtends a half-angle of approximately:

$$
\theta=\tan^{-1}(101.5/3200)\approx1.82^\circ
$$

The intended illumination cone is approximately ±1.8° to ±2.0°, corresponding to approximately NA =
0.032–0.035 in air. Slight mirror overfill is preferred to underfill.

Useful nominal beam diameters for a ±1.8° cone are:

| Distance from source slit | Approx. beam diameter |
|---|---|
| 1 m | 63 mm |
| 2 m | 127 mm |
| 3.2 m | 203 mm |

The mirror's approximately f/7.9 focal ratio should not be confused with this source cone. The source operates
near 2f, at approximately the mirror center of curvature.

### 3.3 Source/imager separation

The two rail pivot centers are separated by 95 mm at the mirror-facing front plate. At 3.2 m this gives
approximately 1.70° total chief-ray separation.

Each rail points toward the mirror and follows its own chief ray. Sliding a fixture along a rail is therefore
predominantly an axial adjustment.

The source slit and cutoff need not occupy exactly the same longitudinal coordinate. Near 2f,

$$
\frac{ds_i}{ds_o}\approx -1
$$

so small source-slit displacement produces approximately equal and opposite conjugate-image displacement.

A useful starting point is about 30–40 mm total slit/cutoff longitudinal staggering, obtained by placing them
approximately ±15–20 mm around nominal 2f. This is an experimental setup adjustment rather than a
fabrication-critical dimension.

### 3.4 Common optical-axis datum

The common optical axis is 72.35 mm above the top surface of the 2020 extrusion.

For optical-head CAD:

- take the rail top surface as z = 0;
- do not reference optical height to the tabletop or support feet;
- small whole-frame pitch/roll errors can be corrected at the mirror.

The optical head uses three coordinate frames with common senses:

- +y forward, toward the mirror;
- +x to the right when looking down from above with the mirror ahead;
- +z up, with the rail top at z = 0.

The frames are right-handed and differ only in where their y axes lie:

- pivot frame: y along the centerline of the front pivot plate, with the origin at the midpoint of its aft
  edge ([§4.2](04-frame.md#42-front-pivot-plate));
- source rail frame: y along the source rail centerline;
- imaging rail frame: y along the imaging rail centerline.

The imaging rail is the right rail, at positive x in the pivot frame, and the source rail is the left. The
phone extends well to the right of its camera axis when sighting along that axis toward the mirror
([§9.1](09-camera-telephoto.md#91-camera)), so this places its overhang on the outer side of the imaging
rail, clear of the source rail and its fixtures.

Each rail frame yaws with its rail, about 0.85° from the pivot frame at nominal
([§4.2](04-frame.md#42-front-pivot-plate)). Its origin is on the rail top at the rail's pivot axis; a fixture
is described with its own rail station at y = 0. In a rail frame the optical axis is at x = 0, z = 72.35 mm,
and pitch, yaw, and roll are rotations about x, z, and y respectively. A rotating fixture may define a local
frame, stated where it is used.

The common post stack is:

- 0.010 in / 0.254 mm metal datum shim;
- 50 mm Thorlabs TR50/M post;
- 22.1 mm post-top-to-optical-axis offset for the SM1 optical holders (Thorlabs SMR1/M: 0.870 in /
  22.098 mm exact);
- total nominal height: 72.35 mm (72.352 mm with the exact SMR1/M offset; the datum is 72.35 mm).

The datum discs are McMaster 2895T62, 3/4 in OD × 0.010 in ±0.0005 in thick, full-hard 18-8 stainless
steel, minimum Rockwell C40. Three discs are used as post datum shims, one under each common post fixture. The
discs provide a consistent metal seating surface for the posts across the central slot in the 2020 rail.

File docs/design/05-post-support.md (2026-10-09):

## 5. Common rail-mounted post support

Three fixtures use the common post/shoe architecture:

1. light source ([§6](06-light-source.md#6-light-source));
2. source-slit flexure head ([§7](07-source-slit.md#7-source-slit));
3. cutoff carriage ([§8](08-cutoff.md#8-cutoff)).

### 5.1 Post

- Thorlabs TR50/M
- 12.7 mm diameter
- 50 mm long

### 5.2 Optical-holder allocation

- light source: 1 × SMR1/M ([§6.1](06-light-source.md#61-assembly-and-stack-order))
- slit head: 1 × SM1RC/M, clamping the printed spigot of the slit-head adapter
  ([§7.6](07-source-slit.md#76-rotation-mount-and-clearances))
- cutoff carriage: 1 × SM1RC/M, clamping the printed spigot of the carriage base plate
  ([§8.1](08-cutoff.md#81-spigot-and-rotation-interface))

The source/slit/cutoff holders preserve the 22.1 mm post-top-to-axis dimension.

### 5.3 Common rail shoe

The common shoe is a printed PLA U-shaped saddle that:

- straddles the 2020 extrusion;
- locks through the rail side channels with M5 screws into the measured slot geometry
  ([§4.1](04-frame.md#41-rails)), using the 20-series slot-6 T-nut hardware;
- leaves the rail top available as the datum surface;
- carries a vertical 12.7 mm through-bore for the TR50/M post.

The post passes through the printed shoe and bottoms on a McMaster 2895T62 0.010 in stainless datum disc
resting on the rail top. The printed PLA does not establish the precision optical height.

The post bore incorporates a single-split clamping collar so that the post can be locked against rotational
movement while remaining fully seated on the metal datum:

- one axial split;
- one transverse clamp screw;
- sufficient axial engagement to resist rocking and rotation;
- rounded stress-relief termination at the bottom of the split;
- generous fillets where the collar merges into the shoe body;
- free-fitting 12.7 mm post bore before clamping.

The clamp provides rotational and lateral retention; post height is still established solely by the post
bottoming on the metal datum disc. The model, with its fit-tested PLA allowances, is
`src/schlieren/parts/rail_shoe.py`.

<p align="center">
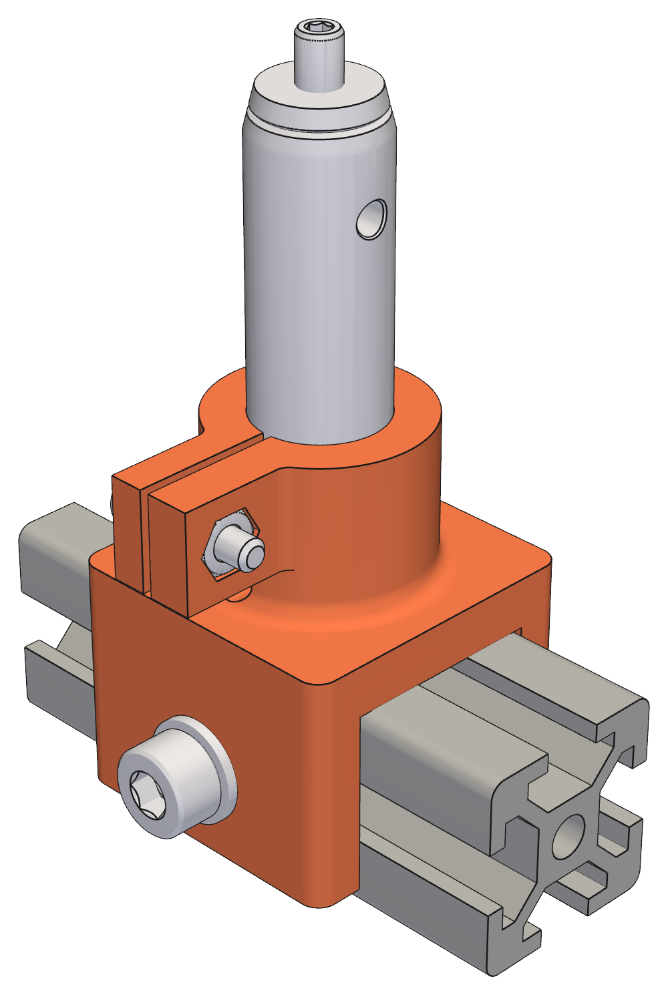
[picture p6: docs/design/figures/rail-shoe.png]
Common rail shoe on the rail and TR50/M post: saddle body, split clamping collar, and clamp ears with the captured-nut pocket
  
  <br>
  <em>Fig. 3. Common rail shoe on rail with TR50/M post</em>
</p>

#### Common printed split-clamp hardware

Every printed split clamp in the apparatus uses the same hardware:

M3 socket-head screw → clearance through one ear → captured M3 hex nut in the opposite ear.

- McMaster 91292A114 — M3 × 0.5 × 12 mm fully threaded 18-8 stainless socket-head screw; 5.5 mm head
  diameter, 3 mm head height, 2.5 mm hex drive. The same screw serves the carriage keeper frame
  ([§8.4](08-cutoff.md#84-cassette-seating)) and the slit head ([§7](07-source-slit.md#7-source-slit)).
- McMaster 91828A211 — full-height M3 × 0.5 18-8 stainless hex nut; 5.5 mm across flats × 2.4 mm high, DIN
  934. The same nut serves the keeper frame, the cassette clamp bars
  ([§8.7](08-cutoff.md#87-cassette-clamp-bars)), and the slit head.
- No washer, nyloc, or threaded insert.

Ear thickness and the approximately 1–2 mm relaxed split gap are designed around the 12 mm screw length.

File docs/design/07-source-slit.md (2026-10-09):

## 7. Source slit

The source slit is a flexure slit head: one flat-printed PLA part carrying both blades, with fine centering
perpendicular to the slit and fine slit-width adjustment, mounted for continuous rotation about the optical
axis in an SM1RC/M on the common post and rail shoe
([§5](05-post-support.md#5-common-rail-mounted-post-support)).

The model is `src/schlieren/parts/slit_head.py` (`uv run slit-head`, with `--show` for the viewer assembly).

The slit needs only about ±2 mm of centering travel, one adjustment axis, and discrete orientations, so it
does not use the cutoff's carriage, plungers, guide rails, keeper frame, datum pins, or cassettes
([§8](08-cutoff.md#8-cutoff)).

The stage-rotation figures below come from a first-order flexure model, not FEA; the printed and assembled head
confirmed the design ([§7.7](#77-fabrication-and-fit)).

### 7.1 Blades and slit widths

The slit uses two Stanley 11-515 backed single-edge scraper blades.

Measured physical blade dimensions:

- length: 1.535 in / 38.99 mm
- width: 0.768 in / 19.51 mm
- thickness at the sharp/flat portion: 0.010 in / 0.254 mm
- thickness at the folded spine: 0.040 in / 1.016 mm

Expected operating slit widths are 0.10–0.30 mm, starting around 0.15–0.20 mm.

Each blade lies flat on its carrier's blade seat, cutting edge toward the slit and overhanging the carrier
edge by about 1.5 mm. No blade pockets, holes, or spine compensation are used; a slight inclination of the
blade toward its folded spine is acceptable, since the optically important geometry is the gap and
parallelism of the two cutting edges.

### 7.2 Architecture

The head is a three-body monolithic flexure:

1. frame — fixed; carries the spigot adapter, the FAS100 #1 insert, and the spring seat;
2. platform — centering stage on a parallelogram flexure from the frame; carries the datum blade and the
   FAS100 #2 insert;
3. width stage — on a nested parallelogram flexure from the platform; carries the movable blade.

Both parallelograms translate perpendicular to the slit. Their parasitic motion (about δ²/L) lies along
the slit, where it is harmless.

Local frame, at rotation 0: slit horizontal, adjustment axis vertical, both FAS100 knobs up. The blade-seat
plane (the carrier front faces) is the front of the head; every other front face stands back 1 mm so the
overhanging blades cannot rub moving or fixed parts.

The head's front faces the light source, so the LED image on the blades is in plain view for centering and
focus ([§6.7](06-light-source.md#67-focus-and-module-interchange)). The spigot adapter, slip ring, and post
are on the mirror side of the blades. In this section "front" and "back" refer to the head, not to the rail
direction.

Envelope: about 80 × 88 × 13 mm, excluding knobs and adapter.

<p align="center">
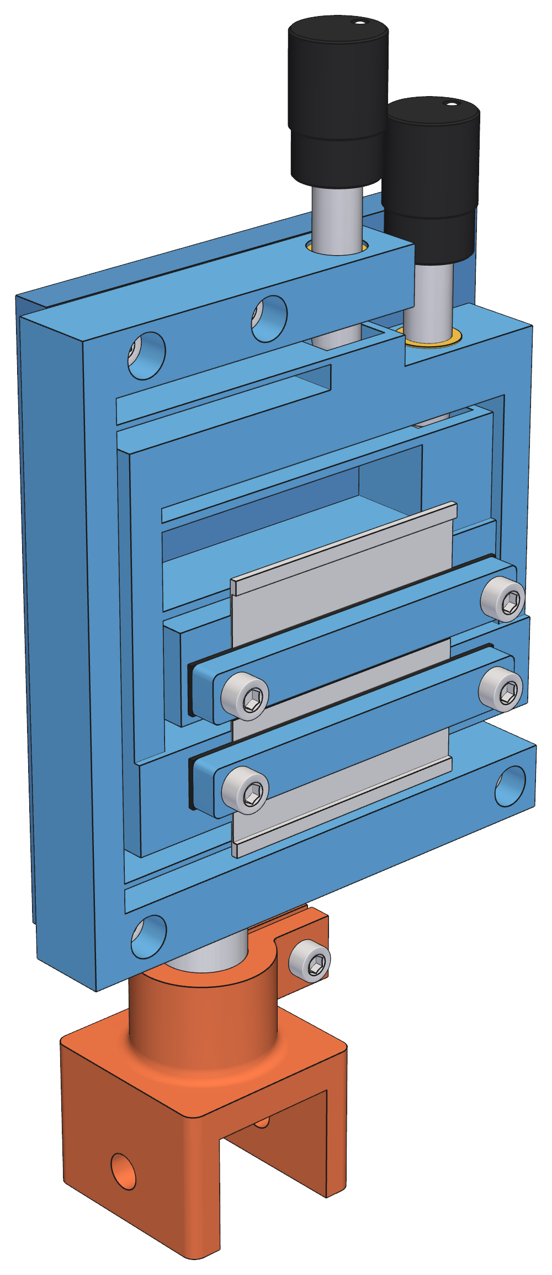
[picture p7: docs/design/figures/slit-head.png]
Flexure slit head from the light-source side: frame, platform and width stage, two blade clamp bars, the two FAS100 adjusters, and the spigot adapter, on its SM1RC/M post and rail shoe
  
  <br>
  <em>Fig. 7. Flexure slit head on its post and rail shoe, seen from the light-source side: blades and clamp bars, FAS100 centering and width adjusters</em>
</p>

Stage rotation in the slit plane would skew the slit against the cutoff (centering) or open it in a taper
(width). Under load each flexure blade bends into an S with its inflection at mid-span, so only a force
through the blades' mid-span needs no axial reaction; the layout keeps the varying drive forces from
twisting the stages:

- FAS100 #1 and the preload spring are coaxial and act on the platform's flexure connectors, so their
  forces cancel and only the small centering-flexure force is unbalanced;
- the two centering blades are at the top and bottom of the platform, about 63 mm apart;
- the two width-stage blades are 12 mm apart, and FAS100 #2 pushes on the width-stage connector.

Closely spaced blades or a spring offset from the screw would not achieve this: a compact layout with 5 mm
blade spacing and the spring 23 mm from the screw gives a constant ~1° platform pre-twist and about 8 mrad of
rotation over the centering travel.

### 7.3 Centering stage

- travel: ±2.0 mm about the as-printed position;
- drive: Thorlabs FAS100 1/4"-80 adjuster, 0.3175 mm per turn (10 µm per about 11° of knob), in a McMaster
  98625A950 brass insert in the frame top bar;
- preload: McMaster 2006N292 spring, coaxial with FAS100 #1, 16.5 mm long at mid travel (9 mm compression),
  about 4.4–6.9 N over the travel; located by printed guide pins inside the coil in pockets in the frame
  bottom bar and the lower platform connector;
- flexure: two 0.8 mm PLA blades, 35.5 mm long, 12 mm deep; about 0.38% peak strain at full travel;
- estimated slit rotation: about 0.05 mrad over the full ±2 mm (0.5 µm across a 10 mm lit slit length).

Measured spring OD: 0.272 in / 6.91 mm (calipers). Spring pockets are Ø7.91 mm (1.0 mm diametral
clearance).

Spring installation: the pockets are closed on all sides except the 3.5 mm flexure gap, and the 16.5 mm
cavity is shorter than the 25.5 mm free length, so the spring has no clear insertion path. It is installed by
compressing it fully and working it into the pockets by hand. If that proves unreliable, the fallback is a
bottom access bore through the frame bottom bar closed by a screwed cap carrying the lower guide pin (not
modeled).

Sensitivity: the iris is about 150 mm before the slit, so moving the slit by d turns the illumination cone
by d/150; at the mirror the beam moves about 21 × d. The ±2 mm travel therefore steers the beam about
±42 mm at the mirror, which covers printed-part and shoe tolerances plus deliberate aiming. For a
horizontal slit this is the only vertical aiming adjustment at the source.

### 7.4 Width stage

- drive: a second FAS100 in a 98625A950 insert in the platform top bar; pushing closes the slit;
- preload: the stage's own flexures, printed so that FAS100 #2 always deflects them 0.8–1.6 mm (about
  0.8–1.6 N, comfortably above the stage's own weight in any orientation);
- usable width adjustment: 0.8 mm;
- flexure: two 1.2 mm PLA blades, 45 mm long, 12 mm apart; about 0.29% peak strain;
- estimated taper: about 0.6 µm across a 10 mm lit slit length per 0.1 mm of width change (about 4.6 µm
  over the full 0.8 mm).

Only the movable blade moves, so a width change shifts the slit center by half the change. For a 0.1 mm
change that is 0.05 mm, which moves the beam about 1 mm at the mirror and needs no recentering of the
slit (the cutoff is readjusted for any width change in any case).

Slit setup:

1. with both clamp bars loose, set the width stage to mid travel with FAS100 #2;
2. clamp the datum blade on the platform carrier;
3. set the movable blade against a true-metric feeler gauge between the cutting edges, pressing gently
   along its length, and clamp it progressively;
4. remove the gauge; thereafter set width with FAS100 #2 from that reference (0.15 mm is about half a
   turn). Re-check parallelism with the gauge after large width changes.

### 7.5 Blade clamping

Each blade is pinched against its carrier by an identical removable printed PLA clamp bar (54 × 7 × 4 mm)
faced with McMaster 9852N37 1/32 in EPDM. The bar bears on the flat portion of the blade about 3 mm back
from the cutting edge, leaving the slit cone clear, and is fastened by two M3 × 12 mm socket-head screws
just beyond the blade ends into M3 hex nuts captured in pockets opening from the carrier back. The common
McMaster 91292A114 screw and 91828A211 nut are used; four of each.

### 7.6 Rotation mount and clearances

A separate printed spigot adapter is bolted to the frame back with four M3 × 12 mm socket-head screws,
counterbored from the head front into M3 nuts captured in the adapter back. The adapter is a flat plate,
held 1.0 mm off the moving stages by two McMaster 93475A210 M3 flat washers (0.4–0.6 mm each) stacked on
each screw between frame and plate. It carries a hollow Ø30.48 mm (SM1 tube OD) spigot with a Ø24 mm light
bore, clamped by the SM1RC/M split ring (Ø30.6 mm bore, 10.16 mm thick, M4 locking screw across the split).

A Ø34 mm shoulder on the spigot is the ring's axial stop: the ring seats against it, which places the
adapter plate 3.5 mm in front of the ring face and 2.2 mm clear of the post at every rotation. Do not clamp
the ring away from the shoulder.

The SM1RC/M keeps the 22.1 mm post-top-to-axis dimension
([§5.2](05-post-support.md#52-optical-holder-allocation)). Loosening the ring rotates the whole head about the
optical axis:

- rotation 0: horizontal slit, vertical centering, knobs up;
- ±90°: vertical slit, horizontal centering, knobs sideways;
- small rotations: slit-to-cutoff parallelism trim.

Calculated clearances over −110° to +110°: at least 2.2 mm to the post body, 4.0 mm to the rail shoe (at
about ±50°, as the corners pass). The TR50/M M4 stud reaches up into the ring's tapped hole and stops about
1.7 mm short of the spigot at its 5.2 mm drawing maximum; this gap is set by the Thorlabs parts, not by this
design. Beyond about ±125° the adapter corners and knobs reach the shoe.

### 7.7 Fabrication and fit

Printed parts: the flexure head, the spigot adapter, and two clamp bars.

- Head: print back face down, so the blade seats on both carriers are the topmost layer and coplanar
  (ironing recommended); the flexure blades are then vertical walls loaded in the layer plane. Keep
  perimeter seams off the four flexure blades.
- Adapter: print front face down, spigot up; no supports.
- Clamp bars: print flat, EPDM face down.
- The insert bores are pilots, finished by a light hand ream with a 5/16 in twist drill to a press fit
  ([§8.3](08-cutoff.md#83-fine-adjustment)). The FAS100 #1 insert is pressed in from the inside with its flange
  on the bar's inner face, so the spring load seats the flange against the bar instead of pushing the insert out;
  the FAS100 #2 flange is outboard, since the platform top bar leaves no room to press it in from the inside
  and it resists only the PLA flexure's restoring force, not a spring.
- The spigot is printed at the SM1 tube nominal, which fits the SM1RC/M.

Hardware: 2 × FAS100, 2 × 98625A950 inserts, 2 × N52 10 × 5 × 2 mm magnet bearing pads (one under each FAS100
ball tip, [§8.3](08-cutoff.md#83-fine-adjustment)), 1 × 2006N292 spring, 8 × M3 × 12 mm socket-head screws, 8
× M3 nuts, 8 × M3 flat washers.

A printed and assembled head (Prusa MINI+, PLA) was evaluated and is fit for purpose: the insert press fit, the
magnet, spring, and other pockets and bores are as sized, the flexures move essentially parallel along both push
axes, the clamp bars, width-stage preload, and adapter-plate clearance work, and the printed spigot fits the
SM1RC/M split ring at the SM1 tube nominal.

**Provisional:** PLA creeps and relaxes under sustained strain, and the width stage is held deflected by its
preload. Check the preload after the head has stood assembled for a few days, and again after warm storage.

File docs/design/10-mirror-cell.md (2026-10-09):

## 10. Mirror cell

### 10.1 Plates and basic architecture

The mirror-cell is constructed from three Baltic birch plywood plates:

- base plate: 11.5 in wide × 7.0 in front-to-back × 1/2 in;
- cell-adjuster plate: 11.5 in wide × 11.0 in high × 1/2 in;
- moving mirror plate: 3/4 in cut to the truncated-hex geometry below.

The base plate provides the structural/tripod-support base and is joined to the cell-adjuster plate by
structural brackets described in [§10.7](#107-structural-brackets). The cell-adjuster plate carries three
fine-adjustment stations ([§10.2](#102-three-adjuster-stations)) which couple it to the moving mirror plate.
The 3/4 in moving mirror plate carries the 203 mm mirror and moves relative to the fixed cell-adjuster plate.

<p align="center">
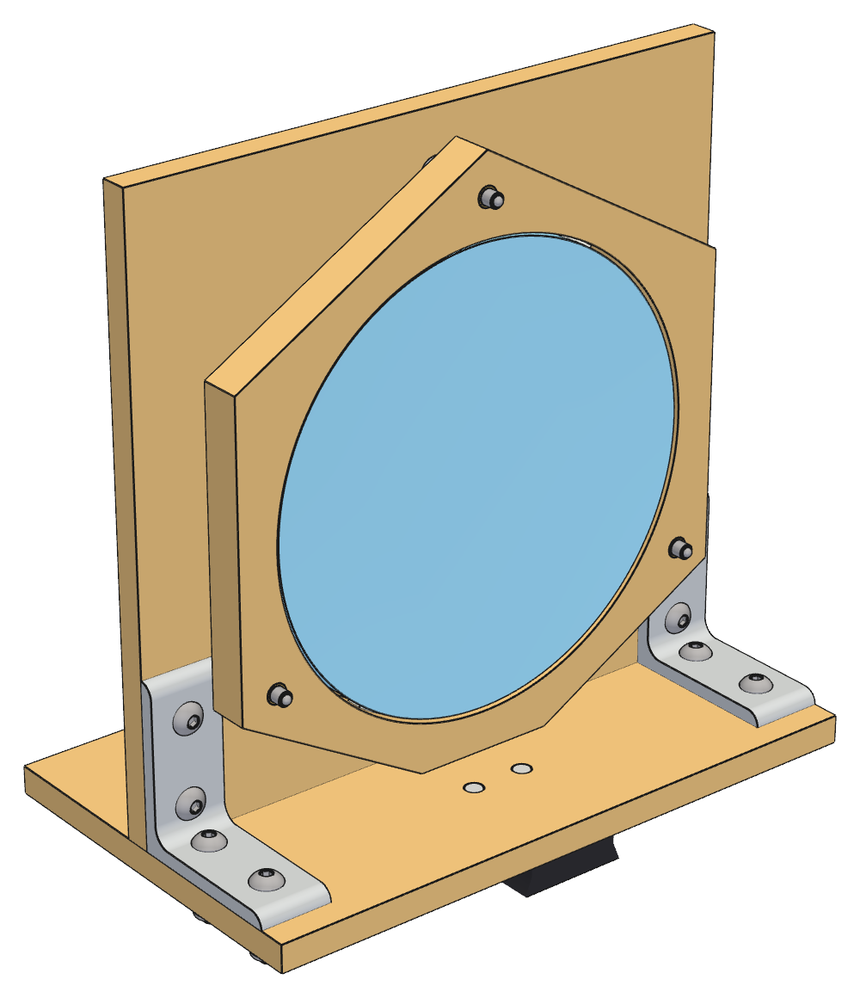
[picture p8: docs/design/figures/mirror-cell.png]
Mirror cell seen from the front: the base plate, the cell-adjuster plate, the moving mirror plate with its 203 mm mirror and three adjuster tips, and the two corner brackets with their screws
  
  <br>
  <em>Fig. 11. Mirror cell from the mirror side: base plate, cell-adjuster plate, moving mirror plate and mirror, and corner brackets</em>
</p>

The cell-adjuster plate is centered left/right on the 11.5 in-wide base. The rear face of the 1/2 in fixed
cell-adjuster plate is 4.000 in aft of the front edge of the 7.0 in-deep base, leaving 3.0 in of
base behind it. Two McMaster 8681N11 structural angle brackets face forward, toward the moving mirror
plate; their measured forward footprint is approximately 3.5 in from the fixed-plate rear face, leaving
approximately 0.5 in of base margin at the front edge. This orientation places the brackets on the mirror side
of the fixed plate so they directly resist the forward overturning moment of the mirror assembly.

Using measured masses of 1.56 kg for the approximately 18 mm-thick mirror, 840 g for the assembled fixed +
moving plates and adjuster hardware, about 318 g for the 11.5 × 7.0 × 1/2 in base plate, and 79 g each for the
two aluminum brackets, the estimated completed mirror-cell fore/aft center of gravity is approximately 3.0 in
/ 76 mm aft of the front edge of the base. A working uncertainty of approximately ±0.2 in / ±5 mm is
conservative. This places the expected center of gravity approximately 1.0 in / 25 mm forward of the rear face
of the fixed cell-adjuster plate. The 130 g CAMVATE removable quick-release plate is centered 0.5 in / 12.7 mm
aft of this location, a small offset that has little effect; final balance is trimmed using the quick-release
system's generous fore/aft sliding travel.

The cell uses:

- three fine-adjustment stations arranged at 120° intervals;
- compression-spring preload at each station;
- spherical washer interfaces for angular accommodation and gravity-load transfer;
- tripod interface through the CAMVATE 577/501/504-style quick-release system and the Sunwayfoto
  LB-68R leveling base.

The moving mirror plate geometry is:

- start from a regular hexagon 11.000 in / 279.4 mm vertex-to-vertex, oriented with one vertex upward;
- the corresponding normal flat radius / apothem is 4.7631 in / 120.98 mm;
- three alternating vertices lie on the three 120° adjuster axes, with the top vertex occupied by one adjuster
  axis and the two lower-side occupied vertices by the other two;
- the three adjuster-hole centers lie on a 4.750 in / 120.65 mm radius from the mirror center;
- the mirror aperture is 8-1/8 in / 206.38 mm diameter, providing approximately 1/16 in radial clearance
  around the nominal 203 mm mirror;
- clip the unused bottom hex vertex with a horizontal chord whose midpoint is 4.7631 in / 120.98 mm below the
  mirror center, matching the original hex apothem. This removes approximately 0.7369 in / 18.72 mm of the
  original lower tip and produces a new lower edge approximately 2.553 in / 64.8 mm long;
- the resulting trimmed moving-plate height is approximately 10.263 in / 260.7 mm from the new lower edge to
  the top vertex.

The nominal clearance from the bottom trimmed edge of the moving mirror plate to the top surface of the base
plate is 3/8 in / 9.53 mm. This places the mirror center approximately 5.138 in / 130.51 mm above the base
top. The top moving-plate vertex then lies approximately 10.638 in / 270.21 mm above the base top, leaving
approximately 0.362 in / 9.2 mm of fixed-plate height above it within the 11.0 in-high cell-adjuster plate.

This truncated-hex geometry preserves the same approximately 0.701 in / 17.8 mm radial plywood width between
the 8-1/8 in mirror aperture and the new bottom edge as exists between the aperture and each original hex
flat. It therefore improves base clearance without introducing a uniquely narrow section.

The moving mirror plate uses 3/4 in Baltic-birch sheet. The 1/2 in Baltic-birch stock is shared with the
tabletop frame and is used for the cell-adjuster plate, base plate, front pivot plate, and rear
rail-support/foot blocks.

### 10.2 Three adjuster stations

There are three equivalent adjuster stations.

The adjusters are Kozak parts:

- TS250-80-2500 1/4 in-80 adjuster
- TB250-80-625 bushing
- KB250-80 adjustment knob

Use one adjuster, one bushing, and one knob at each of the three stations.

<p align="center">
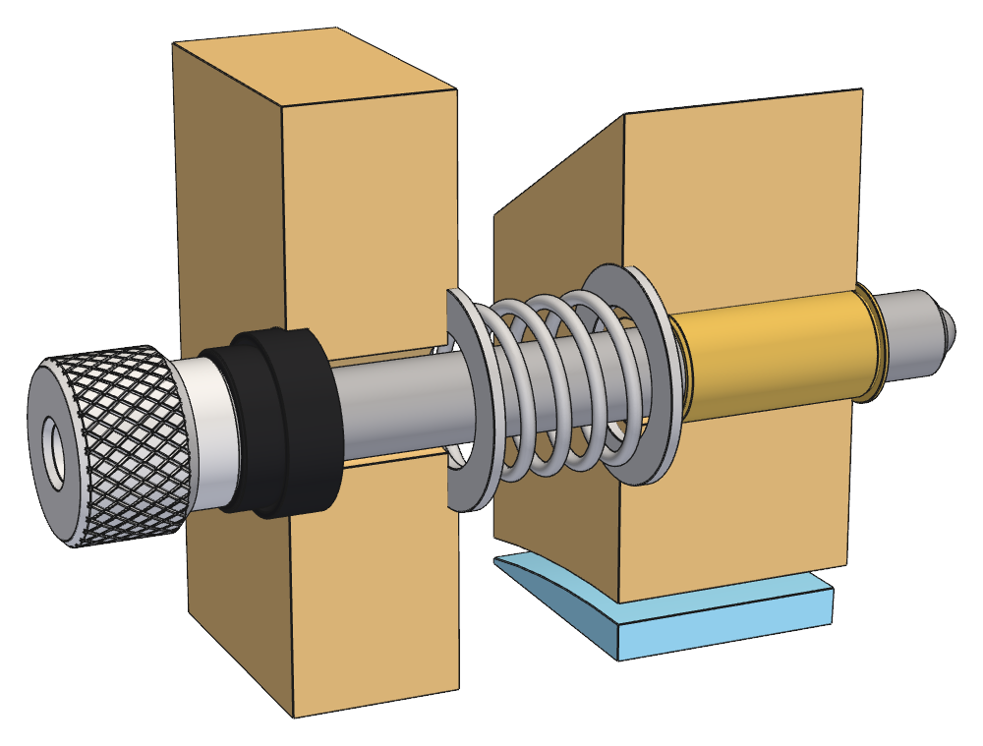
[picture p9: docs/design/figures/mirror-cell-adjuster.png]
Section through one adjuster station: knob, spherical washer pair, cell-adjuster plate, spring between its seat washers, moving plate with bushing, and the adjuster screw
  
  <br>
  <em>Fig. 12. Adjuster station, plywood and mirror cut away: knob, spherical washer pair, spring and seat washers, bushing, and adjuster screw</em>
</p>

Each adjuster station includes a concentric compression spring.

The adjuster bolt passes through the spring and therefore positively retains and laterally locates it. There
is no separate spring pocket or spring bore in the plywood.

#### Adjuster-bushing mounting

Each Kozak TB250-80-625 bushing is bonded directly into the 3/4 in moving mirror plate. No separate metal
bushing carrier is used.

Mounting details:

- the bushing's narrow flange is on the mirror-facing / outboard face of the moving mirror plate, opposite the
  inter-plate spring space; spring/adjuster load therefore tends to seat the flange against the plywood rather
  than pull it away;
- drill the bushing bore 8.0 mm through the Baltic birch, preferably in a drill press with a sharp brad-point
  bit and sacrificial backing to minimize breakout;
- the 0.625 in-long bushing barrel is fully contained within the 3/4 in plate and is bonded over its available
  cylindrical length;
- use WEST SYSTEM G/flex 650 epoxy for the wood-to-metal structural bond;
- bond directly to clean, fresh Baltic-birch bore surfaces; do not CA-harden or pre-seal the bushing bore;
- degrease and lightly abrade the outside of the bushing barrel before bonding without materially reducing its
  diameter;
- wet both the bore and bushing barrel with a thin continuous epoxy film, while keeping epoxy out of the
  internal 1/4 in-80 thread;
- seat the flange fully against the outboard face, remove squeeze-out from both faces, and cure with the
  bushing axis held square to the plate;
- the thin bushing flange is treated primarily as a seating/depth-stop feature. Structural retention is
  provided by the full-barrel epoxy bond and cylindrical bearing of the bushing in the plywood.

This arrangement adds no hardware thickness to the inter-plate gap.

### 10.3 Compression springs and seat washers

Components:

- McMaster 2022N186 compression springs
- McMaster 98017A199 stainless spring-seat washers

Each of the three springs is captured between two seat washers, producing:

- 3 springs
- 6 spring-seat washers
- 6 shallow spring-seat-washer counterbores

The counterbores register the washers; they are not spring pockets.

The nominal wood-face-to-wood-face interplate gap is 0.500 in / 12.7 mm at the neutral mirror
position.

The spring-seat washer counterbores are:

- diameter: 5/8 in (Forstner cutter);
- nominal depth: 1/32 in / 0.03125 in / 0.794 mm;
- use the same nominal depth for all three seats in the moving mirror plate and all three corresponding seats
  in the fixed cell-adjuster plate.

The McMaster 98017A199 washers are approximately 0.028–0.036 in thick, so the 1/32 in recess places
them approximately flush with the plywood surfaces across their thickness tolerance. With the 0.750
in-free-length McMaster 2022N186 springs and the 0.500 in nominal interplate gap, the springs operate at
approximately 0.250 in nominal compression before small washer-thickness and adjustment-position variations.

### 10.4 Spherical washer interfaces

Each of the three adjuster locations uses:

- McMaster 91131A028 spherical washer set
- one shallow close-fitting plywood socket/counterbore.

Total:

- 3 spherical-washer counterbores

These sockets participate in the mirror-cell gravity load path. The washer OD bears against the counterbore
wall, transferring gravity load from the 3/4 in moving mirror plate/adjuster assembly to the fixed 1/2 in
cell-adjuster plate.

Target depth:

- approximately 1/16 in / 1.6 mm

The diameter should be a close free fit, not a loose retention pocket. Final cutter diameter should be
selected against measured washer OD rather than assuming a nominal oversize woodworking dimension.
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

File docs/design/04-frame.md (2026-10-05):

## 4. Tabletop optical frame

<p align="center">
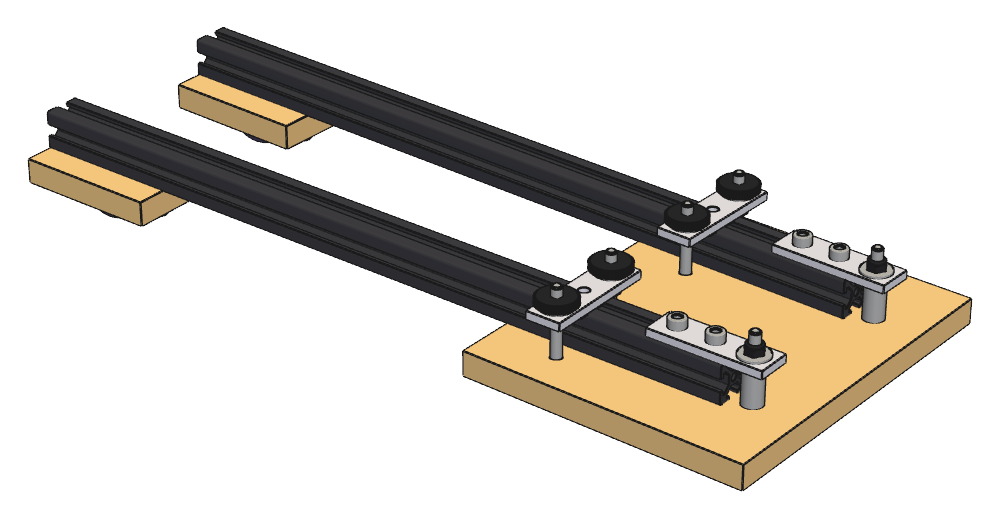
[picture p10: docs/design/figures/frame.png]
Tabletop frame: two 2020 rails pivoted on the plywood front pivot plate under their pivot lugs and yaw straps, each with a rear foot block
  
  <br>
  <em>Fig. 1. Tabletop frame: rails, front pivot plate with pivot lugs and yaw straps, and rear foot blocks</em>
</p>

The model is `src/schlieren/parts/frame.py`.

### 4.1 Rails

- IXGNIJ black-anodized metric 2020 extrusion, Amazon B08Y8N7FD1
- 20 × 20 × 400 mm
- two rails used
- nominal 6 mm European-style slot

There is no rear crossrail.

Measured slot geometry of the extrusion:
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

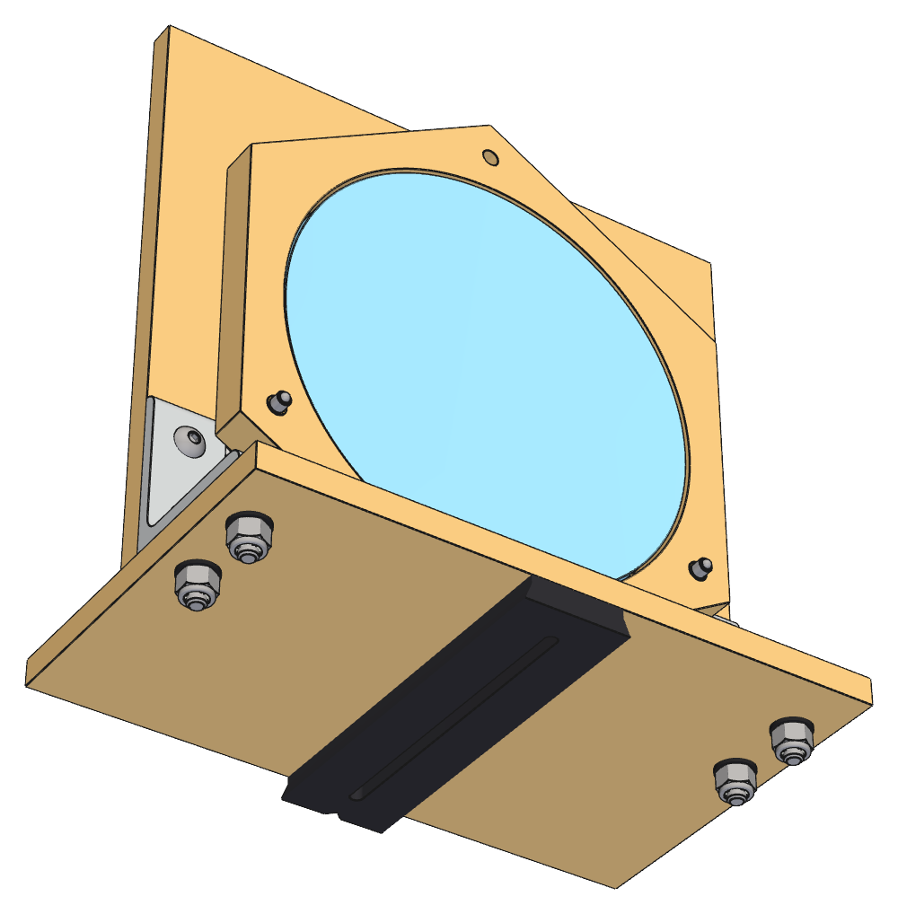
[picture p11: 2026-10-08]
docs/design/figures/mirror-cell-below.png

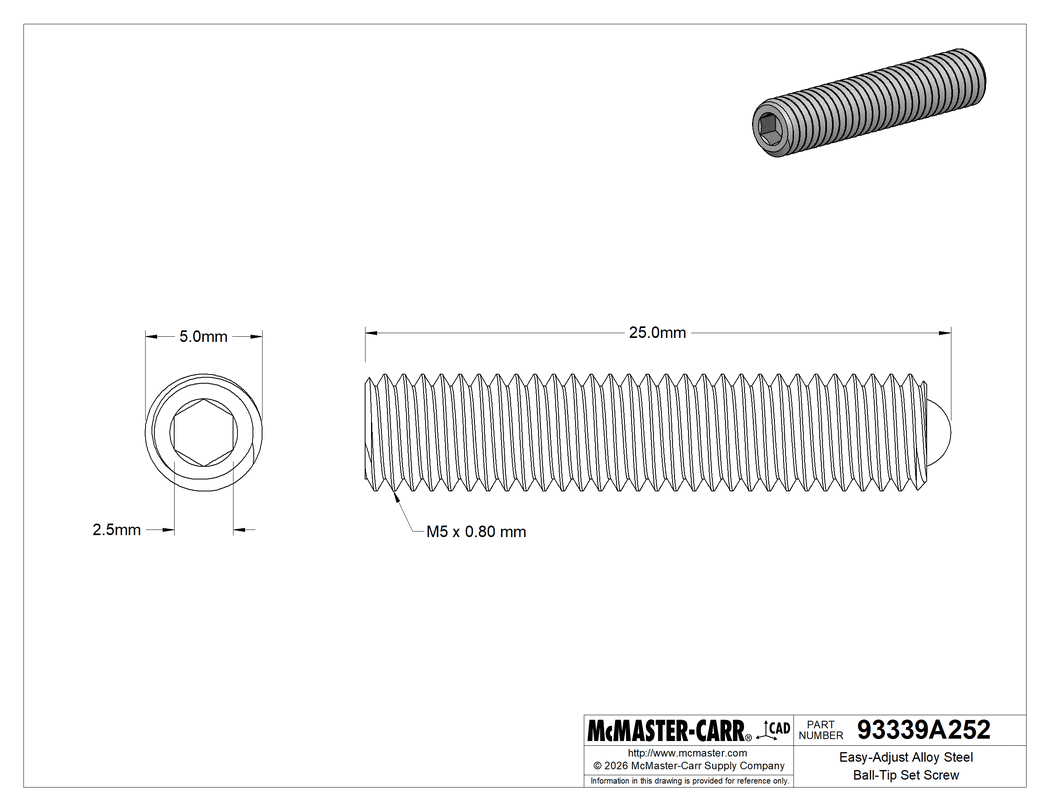
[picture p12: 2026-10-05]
docs/reference/McMaster-93339A252.gif

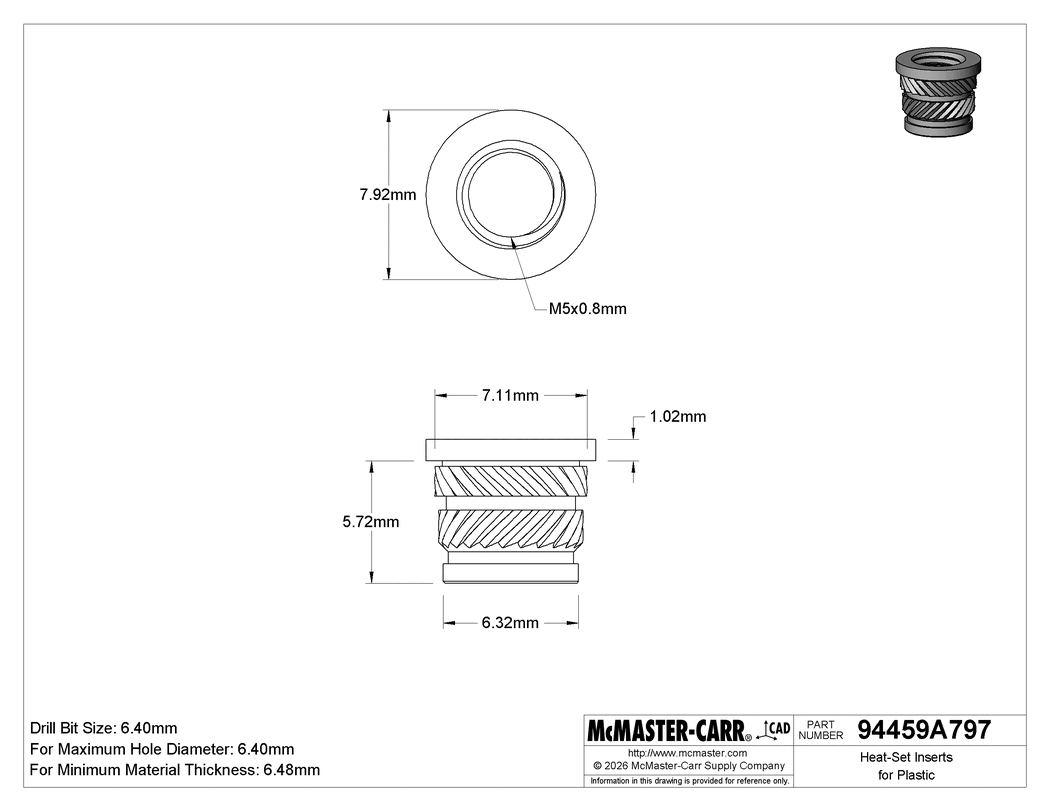
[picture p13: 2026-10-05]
docs/reference/McMaster-94459A797.gif

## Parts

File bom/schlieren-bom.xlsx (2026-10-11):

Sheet: Summary
iPhone Schlieren BOM / Procurement Tracker
Canonical workbook | Generated from bom/bom.csv in Git. Edits made here count only once reconciled into the CSV (reconcile-bom).
Design baseline | docs/design/ fragments in Git (consolidated: schlieren-design).
Quantity model | Qty is the numeric required/allocated amount for that BOM line; package counts do not belong in Qty.
Blank Qty | Quantity is not yet frozen or the item is an as-required consumable/working-stock line.
Package fields | Package Size is units per Purchase Unit where known. Unknown vendor package sizes are intentionally blank.
Entry count
Procurement state | Entries | Subsystem | Entries
In hand |  | Tabletop frame
On order |  | Optical supports
To procure |  | Light source
Specified |  | Source slit
CAD ready |  | Carriages
CAD open |  | Cassettes
 |  | Imager
 |  | Mirror cell
 |  | Shop supplies
Rollup key | Use Vendor + SKU for procurement rollups.
Shared parts | Keep separate BOM rows for separate subsystem allocations; roll them up by Vendor+SKU.
Package math | Vendor/SKU rollups may sum Qty and divide by Package Size where Package Size is known.
Spare/surplus | Unavoidable package surplus is not added to required Qty; track it in procurement/inventory rollups or notes.
Data rule | Do not insert subsystem header or separator rows inside the BOM table.
Specified | Part defined by the design; vendor, SKU, or quantity still to be confirmed.
CAD ready | Printed part with a build123d model in src/schlieren/parts/; ready to print and fit-test.
CAD open | Printed part whose custom geometry is still to be designed.

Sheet: BOM
ID | Subsystem | Qty | Item | Purpose | Vendor | SKU | Pkg Size | Purchase Unit | Procurement state | Source section | Notes
FRM-001 | Tabletop frame | 2 | 400mm T slot 2020 aluminum extrusion | Mounting rails | Amazon | B08Y8N7FD1 | 4 | pack | In hand | §4.1
FRM-002 | Tabletop frame | 1 | Baltic birch plywood panel 12 × 12 × 1/2 in | Rail pivot plate, rail feet | Amazon | B09D941GXR | 4 | pack | In hand | §§4.2, 4.4
FRM-003 | Tabletop frame | 2 | 3-hole straight flat joining plates, aluminum | Rail pivots | Amazon | B0G8DCS7VP | 10 | pack | In hand | §4.3
FRM-004 | Tabletop frame | 2 | M5 x 50 mm socket head screw, 316 SS | Rail pivots | McMaster | 92290A265 | 10 | pack | In hand | §4.3
FRM-005 | Tabletop frame | 2 | M5 x 20 mm unthreaded spacer, SS | Rail pivots | McMaster | 92871A091 | 3 | each | In hand | §4.3
FRM-006 | Tabletop frame | 2 | M5 nyloc nuts, 18-8 SS black oxide | Rail pivot nuts | McMaster | 93625A225 | 10 | pack | In hand | §4.3
FRM-007 | Tabletop frame | 4 | Oversize M5 washers, 15 mm OD | Rail pivot washers | McMaster | 91116A350 | 10 | pack | In hand | §4.3
FRM-008 | Tabletop frame | 4 | M5 x 50 mm socket head screw, 316 SS | Yaw clamp screws | McMaster | 92290A265 | 10 | pack | In hand | §4.3
FRM-009 | Tabletop frame | 2 | 3-hole straight flat joining plates, aluminum | Yaw clamp straps | Amazon | B0G8DCS7VP | 10 | pack | In hand | §4.3
FRM-010 | Tabletop frame | 4 | M5 thumb nuts, low profile black oxide | Yaw clamp tighteners | McMaster | 92815A202 | 10 | pack | In hand | §4.3
FRM-011 | Tabletop frame | 8 | Oversize M5 washers, 15 mm OD | Yaw clamp washers | McMaster | 91116A350 | 10 | pack | In hand | §4.3
FRM-012 | Tabletop frame | 3 | Adhesive-back Sorbothane bumper, 1-1/4" OD, 4 lbs. Max | Soft isolation feet | McMaster | 8215K2 | 3 | each | In hand | §4.4
FRM-013 | Tabletop frame | 3 | Adhesive-back Sorbothane bumper, 1-1/4" OD, 10 Lbs. Max | Backup stiffer isolation feet | McMaster | 8215K6 | 3 | each | In hand | §4.4
FRM-014 | Tabletop frame | 1 | 50 pcs 2020 M5 T nut, roll-in, spring loaded |  | Amazon | B0DP6JBX4Y | 1 | each | In hand | §4.1
FRM-015 | Tabletop frame | 2 | 272 pcs M5 socket screws assortment kit 12.9 steel black zinc |  | Amazon | B0FGV561HZ | 2 | each | In hand | §4.1
FRM-016 | Tabletop frame | 3 | 244 pcs M5 socket screws assortment kit 304 SS |  | Amazon | B0DJP7ZLVC | 3 | each | In hand | §4.1
FRM-017 | Tabletop frame |  | Rubber/EPDM sheet | Yaw strap friction strips | McMaster | 9852N37 |  | sheet | In hand | §4.3 | Two strips (one per yaw strap), cut from the CAS-002 sheet; no separate purchase.
SUP-001 | Optical supports | 3 | Ø12.7 mm optical post, 50 mm, SS |  | Thorlabs | TR50/M | 4 | each | In hand | §5.1 | Three installed (condenser, slit, cutoff stations); fourth in-hand post is spare after the threaded LED module decision.
SUP-002 | Optical supports | 3 | Shim discs, 3/4 in OD x 0.010 ±0.0005 in, SS | Post seats | McMaster | 2895T62 | 5 | pack | In hand | §5.3
SUP-003 | Optical supports | 3 | M3 × 12 mm socket head screw, 18-8 SS | Collar clamp screws | McMaster | 91292A114 | 100 | pack | In hand | §5.3 | Finalized 12 mm length.
SUP-004 | Optical supports | 3 | M3 × 0.5 hex nut, 18-8 SS, 5.5 mm AF × 2.4 mm high | Collar clamp nuts | McMaster | 91828A211 | 100 | pack | In hand | §5.3 | Full-height DIN 934 nut; captured in printed pocket.
SUP-005 | Optical supports | 3 | PLA printed post shoes |  |  |  |  |  | In hand | §5.3
LGT-001 | Light source | 1 | Aspheric Condenser Lens, Ø25 mm, f=20.1 mm, NA=0.60, ARC: 350-700 nm |  | Thorlabs | ACL2520U-A | 1 | each | In hand | §6.1
LGT-002 | Light source | 1 | Ø1" Adjustable lens tube, 0.31" travel range |  | Thorlabs | SM1V05 | 1 | each | In hand | §6.1
LGT-003 | Light source | 1 | SM1 lens tube, 0.30" thread depth | Spacing between lens and iris | Thorlabs | SM1L03 | 1 | each | In hand | §6.1
LGT-004 | Light source | 1 | Adjustable iris |  | Thorlabs | SM1D12 | 1 | each | In hand | §6.1
LGT-005 | Light source | 1 | Ø1" lens mount with SM1 internal threads and no retaining Lip, M4 tap | Post attachment | Thorlabs | SMR1/M | 1 | each | In hand | §6.1
LGT-006 | Light source | 1 | Internally SM1-threaded end cap |  | Thorlabs | SM1CP1 | 1 | each | In hand | §6.1
LGT-007 | Light source | 1 | Snap-on plastic dust cap for SM1 lens tube |  | Thorlabs | SM1EC2 | 5 | pack | In hand | §6.1
LGT-008 | Light source | 1 | Nichia 519A R9080 5000K | White LED | Convoy | 519A R9080 5000K | 3 | each | In hand | §6.2
LGT-009 | Light source | 1 | OSRAM LST1-01F06-GRN1-00 | Green LED | Digikey | 1672-1132-ND | 2 | each | In hand | §6.2
LGT-010 | Light source |  | Heatsink, 6063-T5 non-anodized aluminum, Ø55 mm x 20 mm. | Existing spare stock; former LED heatsink | HeatsinkOnline | 64ASL-8-55 | 4 | each | In hand |  | No longer allocated after the threaded SM1 LED module decision; replaced by LGT-018 (Alpha CN40-40B). Four in hand retained as spares.
LGT-011 | Light source | 4 | M2 × 5 mm button head hex-drive screw 18-8 SS | LED board mounting screws, tapped into SM1CP2M cap | McMaster | 92095A452 | 25 | pack | In hand | §6.4
LGT-012 | Light source | 4 | M2 nylon washers | LED insulating washers | McMaster | 91545A410 |  | pack | In hand | §6.4
LGT-013 | Light source | 1 | ALIENTEK DP100 DC Power Supply Variable, 30V 5A | LED CC/CV power supply | Amazon | B0CWRG6YFM | 1 | each | In hand | §6.5
LGT-014 | Light source | 2 | Cable Assembly, Micro-Fit 3.0 P-S 2ckt 150 mm | LED pigtails | Mouser | 538-214758-1021 | 2 | each | In hand | §6.5
LGT-015 | Light source | 1 | Cable Assembly, Micro-Fit 3.0 R-S 2ckt 600MM | Power supply pigtail | Mouser | 538-214756-1023 | 2 | each | In hand | §6.5
LGT-016 | Light source | 1 | Banana plug set 1 blk 1 red | DP11 connection | Mouser | 565-1825-02 | 1 | each | In hand | §6.5
LGT-017 | Light source | 2 | SM1 end cap, external threads, with center drill mark, anodized aluminum | LED carrier: board on front face, threads into condenser SMR1/M | Thorlabs | SM1CP2M |  | each | On order | §6.2 | One per LED module. Drill/tap: M2 board holes (front), M3 heatsink holes (rear, ~2.5 mm deep), lead pass-through holes at r ≈ 11 mm.
LGT-018 | Light source | 2 | Alpha CN40-40B natural-convection pin-fin heatsink, Ø40 × 40 mm, black anodized | LED module heatsink | Luxeon Star LEDs | CN40-40B |  | each | On order | §6.3 | One per LED module; bolted to SM1CP2M rear. Drill base for M3 screws in open pin cells and for leads.
LGT-019 | Light source | 6 | M3 × 0.5 × 6 mm socket head screw, 18-8 SS | Heatsink-to-cap fasteners | McMaster | 91292A111 | 100 | pack | On order | §§6.2, 6.4 | Three per module. Provisional length (3 mm base + ~3 mm thread into the through-tapped cap; shorter than the cap thickness). Same series as the common 12 mm screw; no 6 mm screws in stock.
SLT-001 | Source slit | 1 | Slip ring for SM1 lens tubes, M4 Tap | Slit-head rotation mount; clamps the adapter spigot | Thorlabs | SM1RC/M | 2 | each | In hand | §7.6 | Second of the two in hand (CAR-002 holds the other).
SLT-002 | Source slit | 2 | Fine adjustment screw with knob, 1/4"-80, 1.00" long | Slit centering and slit-width adjusters | Thorlabs | FAS100 | 3 | each | In hand | §§7.3–7.4 | Shared stock with CAR-005: three in hand, two here, one in the cutoff carriage; no spare.
SLT-003 | Source slit | 2 | 1/4 in-80 inserts | Slit centering and slit-width adjusters | McMaster | 98625A950 | 3 | each | In hand | §§7.3–7.4 | Shared stock with CAR-007: three in hand, two here, one in the cutoff carriage; no spare. Finish printed bores with a 5/16 in drill; a light hand ream gave a good press fit on the first print.
SLT-004 | Source slit | 1 | Compression springs | Centering-stage preload, coaxial with the centering FAS100 | McMaster | 2006N292 | 5 | pack | In hand | §7.3 | Measured OD 0.272 in / 6.91 mm. Installed fully compressed by hand (§7.3). Shared 5-pack with CAR-006.
SLT-005 | Source slit | 2 | N52 Bar Magnet - 10mm L x 5mm W x 2mm H | Hard bearing pads under the FAS100 ball tips | Amazon | B0DMCY4FN1 | 120 | pack | In hand | §§7.3–7.4 | Shared pack with CAR-012 and CAM-009.
SLT-006 | Source slit | 2 | Razor blade, Stanley 11-515 | Slit blades (datum and movable) | Amazon | B000NNIIQM | 100 | pack | In hand | §7.1 | Shared 100-pack with CAS-007.
SLT-007 | Source slit | 8 | M3 × 12 mm socket head screw, 18-8 SS | Blade clamp bars (4) and adapter-to-head (4) | McMaster | 91292A114 | 100 | pack | In hand | §§7.5–7.6 | Shared common 100-pack.
SLT-008 | Source slit | 8 | M3 × 0.5 hex nut, 18-8 SS, 5.5 mm AF × 2.4 mm high | Captive nuts for blade clamp bars (4) and adapter (4) | McMaster | 91828A211 | 100 | pack | In hand | §§7.5–7.6 | Shared common 100-pack (see CAS-004).
SLT-009 | Source slit | 8 | M3 flat washer, 3.2 mm ID × 7 mm OD, 18-8 SS | Adapter spacer washers, two per adapter screw | McMaster | 93475A210 | 100 | pack | In hand | §7.6 | Two stacked per screw set the ~1 mm adapter standoff. Shared 100-pack with CAS-005.
SLT-010 | Source slit | 1 | PLA printed flexure slit head |  |  |  |  |  | CAD ready | §7.2 | CAD in src/schlieren/parts/slit_head.py; printed and evaluated, fit for purpose (§7.7).
SLT-011 | Source slit | 1 | PLA printed slit-head spigot adapter |  |  |  |  |  | CAD ready | §7.6
SLT-012 | Source slit | 2 | PLA printed slit-head blade clamp bars |  |  |  |  |  | CAD ready | §7.5
CAR-001 | Carriages |  | SM1 lens tube, 1.50" Thread Depth | Existing stock; former carriage-tube allocation | Thorlabs | SM1L15 | 2 | each | In hand |  | No longer allocated: the cutoff carriage mounts in the SM1RC/M on an integral printed spigot (§8.1); both tubes in hand are spare.
CAR-002 | Carriages | 1 | Slip ring for SM1 lens tubes, M4 Tap | Post attachment | Thorlabs | SM1RC/M | 2 | each | In hand | §8.1 | Cutoff carriage. The second in-hand ring is allocated to the slit head (SLT-001).
CAR-005 | Carriages | 1 | Fine adjustment screw with knob, 1/4"-80, 1.00" long | Cassette positioner | Thorlabs | FAS100 | 3 | each | In hand | §8.3 | Three in hand: one for the cutoff carriage, two for the slit head (SLT-002); no spare.
CAR-006 | Carriages | 1 | Compression springs | Cassette counter-force plunger | McMaster | 2006N292 | 5 | pack | In hand | §8.3 | Shared 5-pack with the slit-head preload spring (SLT-004).
CAR-007 | Carriages | 1 | 1/4 in-80 inserts | Cassette positioner | McMaster | 98625A950 | 3 | each | In hand | §8.3 | Three in hand: one for the cutoff carriage, two for the slit head (SLT-003); no spare.
CAR-008 | Carriages |  | 4 mm × 45 mm shoulder screw, 18-8 SS | Existing stock; former spring guide / retract handle | McMaster | 91273A377 | 2 | each | In hand |  | No longer allocated: the spring seats in printed cups and the plunger retracts by a thumb tab (§8.5); both screws in hand are spare.
CAR-009 | Carriages | 3 | Brass escutcheon pins | Cassette interface datums | McMaster | 97936A109 | 300 | pack | In hand | §8.4 | Cutoff carriage only.
CAR-010 | Carriages | 1 | PLA printed carriage bodies |  |  |  |  |  | CAD ready | §8.1 | Cutoff carriage only.
CAR-012 | Carriages | 1 | N52 Bar Magnet - 10mm L x 5mm W x 2mm H | Hard bearing pads for FAS100-driven plungers | Amazon | B0DMCY4FN1 | 120 | pack | In hand | §8.3 | Nickel-plated rectangular magnets; one hard contact insert for the FAS100-driven PLA plunger of the cutoff carriage.
CAR-013 | Carriages | 1 | PLA printed open-center keeper frames | Retain plunger guide ears while leaving cassette-loading aperture open |  |  |  |  | CAD ready | §8.4 | Perimeter frame; eight M3 screws (four end, four side in lugs); 3.0 mm side members, with a 5 mm-side-member fallback keeper if lift is excessive; carries the end-wall spring-cup roof (§8.5). Cutoff carriage only.
CAR-014 | Carriages | 8 | M3 × 12 mm socket head screw, 18-8 SS | Keeper-frame fasteners (four end + four side) | McMaster | 91292A114 | 100 | pack | In hand | §8.4 | Reuse common M3 × 12 mm stock. Heads bear directly on PLA in ~0.5 mm recesses; tighten only to a light snug; verify printed fit.
CAR-015 | Carriages | 8 | M3 × 0.5 hex nut, 18-8 SS, 5.5 mm AF × 2.4 mm high | Keeper-frame captive nuts | McMaster | 91828A211 | 100 | pack | In hand | §8.4 | Full-height DIN 934 nut. ~2.5 mm captive hex pocket from carriage back, leaving ~1.5 mm PLA floor above pocket.
CAS-001 | Cassettes | 6 | PLA printed cassettes |  |  |  |  |  | CAD ready | §8.6 | The source slit no longer uses a cassette (§7); quantity to be re-confirmed for the cutoff cassettes.
CAS-002 | Cassettes | 1 | Rubber/EPDM sheet | Retaining bar friction pads | McMaster | 9852N37 | 1 | sheet | In hand | §§7.5, 8.7 | Also faces the two slit-head blade clamp bars (§7.5).
CAS-003 | Cassettes | 12 | M3 × 14 mm 90° flat-head socket screw, 18-8 SS | Retaining bar screws | McMaster | 92125A133 | 100 | pack | In hand | §8.7 | Fit-tested on built cassettes with 4 mm bars: full nut engagement, head flush in countersink.
CAS-004 | Cassettes | 12 | M3 × 0.5 full-height hex nut, 18-8 SS | Retaining bar nuts | McMaster | 91828A211 | 100 | pack | In hand | §8.7 | Shared 100-pack: 33 total nuts now allocated across split clamps, keeper frames, cassette retaining bars, the slit head, and the lens collars; 67 spare.
CAS-005 | Cassettes | 12 | M3 flat washer, 3.2 mm ID × 7 mm OD, 18-8 SS | Retaining bar washers | McMaster | 93475A210 | 100 | pack | In hand | §8.7 | Under exposed nut, on printed retaining bar. Shared 100-pack with the slit-head spacer washers (SLT-009).
CAS-006 | Cassettes |  | Razor blade, Stanley 11-515 | Existing stock; former slit-cassette allocation | Amazon | B000NNIIQM | 100 | pack | In hand |  | No longer allocated after the flexure slit head decision (§7); the slit blades are SLT-006.
CAS-007 | Cassettes | 1 | Razor blade, Stanley 11-515 | Cutoff cassette | Amazon | B000NNIIQM | 100 | pack | In hand | §8
CAS-008 | Cassettes | 1 | Magnet wire, 44 AWG (~0.0508 mm bare conductor) | Dark-field cutoff filament | Amazon | B0F29JW8CF |  |  | In hand | §8.8 | Enamel-coated copper. Finished outside diameter will be slightly larger than the nominal bare-conductor diameter.
CAS-009 | Cassettes | 1 | Magnet wire, 34 AWG (~0.160 mm bare conductor) | Dark-field cutoff filament | Amazon | B07P2HJJP6 |  |  | In hand | §8.8 | Enamel-coated copper. Finished outside diameter will be slightly larger than the nominal bare-conductor diameter.
CAS-010 | Cassettes | 1 | Magnet wire, 30 AWG (~0.255 mm bare conductor) | Dark-field cutoff filament | Amazon | B07GBMKMKY |  |  | In hand | §8.8 | Enamel-coated copper. Finished outside diameter will be slightly larger than the nominal bare-conductor diameter.
CAS-011 | Cassettes | 1 | Rosco Roscolux Designer Color Selector Swatchbook - 3 x 6 | Cutoff cassettes | Amazon | B074V94RNR | 1 | each | In hand | §8.9
CAM-001 | Imager | 1 | iPhone | Imager | Apple | iPhone 17 | 1 | each | In hand | §9.1
CAM-002 | Imager | 1 | iPhone camera app | Imager | Blackmagic Design | Blackmagic Camera | 1 | each | In hand | §9.1
CAM-003 | Imager | 1 | Telephoto lens, 17mm | Imager | iOgrapher | proSnap 7× | 1 | each | In hand | §9.2
CAM-004 | Imager | 4 | Ball-tip jack screws | Lens cradle adjusters | McMaster | 93339A252 | 4 | each | In hand | §9.7 | Two under each lens collar. All four of the pack in hand are allocated; no spare.
CAM-005 | Imager | 6 | M5 flanged heat-set inserts | Lens cradle adjusters and yoke joints | McMaster | 94459A797 | 25 | pack | In hand | §9.7 | Four set in the yoke arms (one per adjuster) and two in the yoke column feet for the joint screws (CAM-016). One pack of 25 in hand; 19 spare.
CAM-006 | Imager | 4 | M5 thumb nuts, low profile black oxide | Lens cradle adjuster handwheels | McMaster | 92815A202 | 10 | pack | In hand | §9.7 | Threadlocked mid-screw. Shared 10-pack with the yaw clamp thumb nuts (FRM-010).
CAM-007 | Imager | 1 | PLA printed phone rest | Roll support under the phone's lower edge |  |  |  |  | CAD open | §9.6 | Phone-specific rail shoe with an arm carrying the rest rod. Retainer and safety catch not yet designed.
CAM-008 | Imager | 1 | PLA printed lens cradle shoe | Rail-shoe saddle that carries the two yokes |  |  |  |  | CAD ready | §9.5 | Lens-specific. Two locating walls and a countersunk M5 hole per yoke; two M5 side-slot clamp holes.
CAM-009 | Imager | 3 | N52 Bar Magnet - 10mm L x 5mm W x 2mm H | Hard bearing pads under three lens-cradle screw tips | Amazon | B0DMCY4FN1 | 120 | pack | In hand | §§9.5–9.7 | Nickel-plated rectangular magnets, 10 mm side across the rail; the fourth screw tip sits in a rod groove (CAM-010).
CAM-010 | Imager | 2 | Ø3 × 10 mm 18-8 stainless dowel pin, ISO 2338 m6 | Groove rods at the fourth lens-cradle screw | McMaster | 91585A351 | 50 | pack | On order | §§9.5–9.7 | Chamfered ends. Two installed, lying across the rail in the aft collar pad pocket; one pack of 50.
CAM-011 | Imager | 2 | PLA printed lens collars | Split clamps on the lens barrel, carrying the adjuster pads |  |  |  |  | CAD ready | §9.5 | Two collars for the 37 mm barrel, identical except that the aft collar's left pad pocket seats the groove rods (CAM-010) in place of a magnet.
CAM-012 | Imager | 2 | M3 × 12 mm socket head screw, 18-8 SS | Lens collar clamp screws | McMaster | 91292A114 | 100 | pack | In hand | §9.5 | Shared common 100-pack. One screw per collar.
CAM-013 | Imager | 2 | M3 × 0.5 hex nut, 18-8 SS, 5.5 mm AF × 2.4 mm high | Lens collar clamp nuts | McMaster | 91828A211 | 100 | pack | In hand | §9.5 | Shared common 100-pack (see CAS-004). One nut per collar.
CAM-014 | Imager | 2 | Oil-resistant Buna-N O-ring, 2 mm wide × 40 mm ID, 70A, round | Lens cradle retaining bands | McMaster | 9262K203 | 25 | pack | On order | §9.5 | One endless ring per collar, on the bare barrel beside the yoke and hooked on its peg. About 19% stretch gives about 3 N per leg (calculated, modulus assumed). If too tight, 41 mm ID is McMaster 9262K694 (pack of 50).
CAM-015 | Imager | 2 | PLA printed lens cradle yokes | Carry the adjuster inserts and the retaining-band pegs |  |  |  |  | CAD ready | §9.5 | Printed on their side; each bolted to the cradle shoe with one countersunk M5 screw (CAM-016) into a heat-set insert (CAM-005).
CAM-016 | Imager | 2 | M5 × 0.8 × 10 mm 18-8 stainless hex-drive flat head screw, 90° | Yoke-to-shoe joint screws | McMaster | 92125A208 | 100 | pack | On order | §§9.5, 9.7 | 10 mm head, 3 mm hex drive. Each screws up through the cradle shoe deck into a heat-set insert in the yoke foot.
CAM-017 | Imager | 1 | Ø4 × 20 mm 18-8 stainless dowel pin, ISO 2338 m6 | Phone rest rod | McMaster | 91585A457 | 25 | pack | On order | §9.6 | Chamfered ends. Lies along the rail in the half-round seat of the phone rest arm (CAM-007); one pack of 25.
MIR-001 | Mirror cell | 1 | Skyoptikst D203F1600 spherical mirror, Ø203 mm, f=1600 mm |  | Amazon | B0B5RR41CT | 1 | each | In hand | §10.5
MIR-002 | Mirror cell | 2 | Baltic birch plywood panel 12 × 12 × 1/2 in | Base and adjuster plates | Amazon | B09D941GXR | 4 | pack | In hand | §10.1
MIR-003 | Mirror cell | 1 | Baltic birch plywood panel 12 × 12 × 3/4 in | Mirror plate | Amazon | B0GL9G45GH | 1 | each | In hand | §10.1
MIR-004 | Mirror cell | 3 | 1/4-80 TPI Imperial fine adjustment screws, 2.5 in |  | Kozak | TS250-80-2500 | 3 | each | In hand | §10.2
MIR-005 | Mirror cell | 3 | Imperial Fine Adjustment Carrier Bushings |  | Kozak | TB250-80-625 | 3 | each | In hand | §10.2
MIR-006 | Mirror cell | 3 | Imperial Adjustment Knobs |  | Kozak | KB250-80 | 3 | each | In hand | §10.2
MIR-007 | Mirror cell | 3 | Leveling Washer, Two Piece, 1/4" Screw Size, Black-Oxide Steel | Spherical washers | McMaster | 91131A028 | 3 | each | In hand | §10.4
MIR-008 | Mirror cell | 3 | Compression Springs, 0.75" Long, 0.5" OD, 0.424" ID |  | McMaster | 2022N186 | 5 | pack | In hand | §10.3
MIR-009 | Mirror cell | 6 | Washer for 3/8" washer, 0.390" ID, 0.028" to 0.036" thick, 18-8 SS | Spring seat washers | McMaster | 98017A199 | 100 | pack | In hand | §10.3
MIR-010 | Mirror cell | 2 | 3" Long Corner Bracket, aluminum | Adjuster plate to base plate mounting | McMaster | 8681N11 | 2 | each | In hand | §10.7
MIR-011 | Mirror cell |  | 5/16" × 1-1/2" hex-drive flat-head screw, 316 SS | Existing alternate/fallback bracket screw stock | McMaster | 90585A587 | 5 | pack | In hand | §10.7 | Previously baseline bracket screw; retained as in-hand alternate stock after corner-clearance review.
MIR-012 | Mirror cell | 8 | 5/16"-18 heavy-profile nylon-insert locknut, 18-8 SS | Adjuster plate to base plate mounting | McMaster | 90099A030 | 5 | pack | In hand | §10.7 | Eight installed, four per bracket. Two 5-packs in hand (10 nuts, two spare).
MIR-013 | Mirror cell | 8 | 5/16" SAE washer, 0.344" ID × 0.688" OD, 18-8 SS black oxide | Adjuster plate to base plate mounting | McMaster | 96659A134 | 25 | pack | In hand | §10.7 | Eight installed, one under each bracket locknut.
MIR-015 | Mirror cell | 4 | 1/4"-20 × 1-1/2" flat-head screws | Existing spare stock; former C2564 tripod-interface hardware | McMaster | 94518A525 | 4 | each | In hand |  | No longer allocated to the active tripod interface after transition to the CAMVATE 577/501/504 quick-release system; retain as in-hand spare hardware.
MIR-017 | Mirror cell | 4 | 1/4"-20 flex-top locknuts | Existing spare stock; former C2564 tripod-interface hardware | McMaster | 91839A123 | 5 | pack | In hand |  | No longer allocated to the active tripod interface after transition to the CAMVATE 577/501/504 quick-release system; retain as in-hand spare hardware.
MIR-018 | Mirror cell | 4 | 1/4" thin washers | Existing spare stock; former C2564 tripod-interface hardware | McMaster | 98019A255 | 10 | pack | In hand |  | No longer allocated to the active tripod interface after transition to the CAMVATE 577/501/504 quick-release system; retain as in-hand spare hardware.
MIR-023 | Mirror cell | 4 | M4 × 0.7 × 16 mm 90° flat-head hex-drive screw, 18-8 stainless | Provisional quick-release plate mounting screw; short-length option | McMaster | 92125A194 | 100 | pack | In hand | §10.9 | Order one pack. Four screws are the provisional installed quantity if this length matches the measured CAMVATE plate thickness; otherwise use MIR-024.
MIR-024 | Mirror cell | 4 | M4 × 0.7 × 18 mm 90° flat-head hex-drive screw, 18-8 stainless | Provisional quick-release plate mounting screw; long-length option | McMaster | 92125A196 | 100 | pack | In hand | §10.9 | Order one pack. Four screws are the provisional installed quantity if this length matches the measured CAMVATE plate thickness; otherwise use MIR-023.
MIR-025 | Mirror cell | 1 | CAMVATE Manfrotto-Type Quick Release Assembly with Sliding Plate Camera Mount | Mirror-cell quick-release / tripod interface | Amazon | B0B2WBC921 | 1 | each | In hand | §10.9 | Complete 577/501/504-compatible quick-release assembly with removable sliding plate and receiver. Exact removable-plate hole pattern and final M4 screw length to be verified on arrival.
MIR-019 | Mirror cell | 1 | DOWSIL 737 clear silicone, 3 fl. oz. | Mirror mounting | McMaster | 7587A25 | 1 | each | In hand | §10.5
MIR-020 | Mirror cell | 1 | Adhesive backed F1 felt | Safety retainer padding | McMaster | 8334K15 | 1 | sheet | In hand | §10.8
MIR-021 | Mirror cell | 3 | PLA printed front safety retainers |  |  |  |  |  | CAD open | §10.8
MIR-022 | Mirror cell |  | 5/16"-18 × 1-3/8" hex-drive flat-head screw, 316 SS | Existing alternate bracket screw stock | McMaster | 90585A997 | 5 | pack | In hand | §10.7 | Former baseline bracket screw; retained as in-hand alternate stock after the change to button-head screws (MIR-026).
MIR-026 | Mirror cell | 8 | 5/16"-18 × 1-3/8" 316 stainless button-head hex-drive screw | Bracket screws, heads on the bracket | McMaster | 98164A527 | 5 | pack | On order | §10.7 | Four per bracket, two through the plate and two through the base; eight installed, so order two 5-packs (two spare). 3/16 in hex drive; head Ø0.547 in × 0.166 in. Pushed through from the bracket side, with MIR-013 washers and MIR-012 locknuts behind the plywood. Thread projects about 0.12 in past the locknut.
SHP-001 | Shop supplies | 1 | Loctite 271 threadlocker, .34 fl. oz. |  | McMaster | 91458A160 | 1 | each | In hand | §9.5
SHP-002 | Shop supplies | 1 | Heat-set installation tip |  | McMaster | 92160A327 | 1 | each | In hand | §9.5
SHP-003 | Shop supplies | 1 | Optical spanner wrench |  | Amazon | B0CKSL364Q | 1 | each | In hand
SHP-004 | Shop supplies | 1 | Metric feeler gauge set | Source-slit blade spacing | Amazon | B07XPD9L1C | 1 | each | In hand | §7.4
SHP-005 | Shop supplies | 1 | M2 tap | LED board mounting into SM1CP2M cap | McMaster | 8305A78 | 1 | each | In hand | §6.4 | Plug chamfer; sufficient for the through M2 holes.
SHP-006 | Shop supplies | 1 | M2 tap drill, 1.6mm | LED mounting | McMaster | 2979N13 | 1 | each | In hand | §6.4
SHP-007 | Shop supplies |  | 18 AWG wire | LED wiring |  |  |  |  | In hand | §6.5
SHP-008 | Shop supplies |  | Heat-shrink tubing | LED wiring |  |  |  |  | In hand
SHP-009 | Shop supplies |  | USB-C chargers/cables | DP100 power |  |  |  |  | In hand
SHP-010 | Shop supplies |  | Thermal compound | LED heatsink interfaces |  |  |  |  | In hand | §6.4
SHP-011 | Shop supplies | 1 | Loctite 4061 cyanoacrylate adhesive, 0.7 fl. oz., low viscosity (~20 cP) | Plywood fiber conditioning and localized tack bonds | McMaster | 1818A45 | 1 | each | In hand | §§6.2, 7, 8.4, 10.4 | Use sparingly: wick into Baltic-birch fibers for spherical-washer sockets; use needle-sized localized drops for PLA/metal calibration tacks and captive screw retention. No accelerator required.
SHP-012 | Shop supplies | 1 | UHMW Sheet 1/8" x 12" x 12" | Mirror mount releasing assembly surface | US Plastics | 46489 | 1 | each | In hand | §10.6
SHP-013 | Shop supplies |  | Soldering tools / supplies | LED wiring |  |  |  |  | In hand
SHP-014 | Shop supplies | 1 | West System G/Flex 650 Epoxy Adhesive, 2 x 4 oz | Mirror cell adjuster sleeves, spring seat washer tack | Amazon | B002IZFPQE | 1 | each | In hand | §10.2
SHP-015 | Shop supplies | 1 | Silicone grease, clear, NLGI 1 | PLA carriage sliding-interface lubricant | McMaster | 1418K51 | 1 | each | In hand | §8.4 | Use only a trace film on dressed PLA-on-PLA sliding interfaces.
SHP-016 | Shop supplies | 1 | White lithium grease, NLGI #2 | Light grease for mirror-cell spherical washer interfaces | Lucas Oil Products |  | 1 | each | In hand | §10.4 | Existing shop stock inspected 2026-09-16 and appears usable.
SHP-017 | Shop supplies | 1 | 1/2" Forstner bit, standard-point smooth-finish | Spherical-washer counterbores | McMaster | 2890A56 | 1 | each | In hand | §10.4 | Use in drill press for shallow close-fit spherical-washer sockets; test in scrap Baltic birch before cutting final plate.
SHP-018 | Shop supplies | 1 | 5/8" Forstner bit, standard-point smooth-finish | Spring-seat washer counterbores | McMaster | 2890A58 | 1 | each | In hand | §10.3 | Use in drill press for shallow spring-seat-washer registration counterbores; test depth/fit in scrap first.
SHP-019 | Shop supplies | 1 | M4 × 0.7 high-speed-steel plug-chamfer hex-bit tap | Tap CAMVATE quick-release plate mounting holes | McMaster | 1021N23 | 1 | each | In hand | §10.9 | Use with 3.3 mm tap drill; exact hole locations await measurement of the delivered plate.
SHP-020 | Shop supplies | 1 | 3.3 mm black-oxide HSS jobber-length drill bit | M4 × 0.7 tap drill for CAMVATE quick-release plate; M3 heatsink clearance holes | McMaster | 2958A64 | 1 | each | In hand | §§6.4, 10.9 | Standard 3.3 mm tap-drill size for M4 × 0.7. Also drills the Ø3.3 M3 clearance holes in the heatsink base (§6.4).
SHP-021 | Shop supplies | 1 | Loctite 243 medium-strength removable threadlocker, 0.34 fl. oz. | Removable thread retention for quick-release plate mounting screws | McMaster | 91458A115 | 1 | each | In hand | §10.9 | Apply only after fit and screw length are validated; preferred over high-strength Loctite 271 for this serviceable joint.
SHP-022 | Shop supplies | 1 | Rosco Photofoil matte black aluminum wrap, 12"x10' | Opaque masking / thin-sheet cutoff experiments | Fullcompass | 01001-1210 | 1 | pack | In hand | §§8, 8.7 | Retained as general shop stock for opaque masking and thin-sheet cutoff experiments.
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

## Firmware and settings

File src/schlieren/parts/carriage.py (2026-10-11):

"""Preliminary five-piece cutoff carriage, design §8.

Local XY is the cassette plane, +Y points toward the FAS100, +Z is the
cassette-loading side, which faces the mirror (§8.1). Z=0 is the plate back, not the rail-height datum.
The rear shouldered spigot, clamped directly by the SM1RC/M, is integral with the base. Dimensions beyond
explicit baseline interfaces are provisional first-print targets; no purchased threads are modeled.
The base and guide frame are one stock body split at the top of the deck; `build_print_layout` gives the
parts as exported, with the base flipped spigot-up and the two plungers laid out side by side.
"""

from dataclasses import dataclass
from itertools import pairwise
from math import cos, pi, radians, tan

from build123d import (
    Axis,
    Compound,
    Plane,
    Polygon,
    Pos,
    Rot,
    chamfer,
    extrude,
    mirror,
)

from schlieren.cad import (
    CUT_OVERRUN,
    assembly,
    compression_spring,
    floor_box,
    labeled,
    x_cylinder,
    y_cone,
    y_cylinder,
    z_cylinder,
    z_hex,
)
from schlieren.hardware import (
    FAS100_PITCH,
    FAS100_THREAD_LENGTH,
    INSERT_98625A950_BODY_DIAMETER,
    INSERT_98625A950_BODY_LENGTH,
    INSERT_98625A950_FLANGE_DIAMETER,
    INSERT_98625A950_FLANGE_THICKNESS,
    INSERT_98625A950_LENGTH,
    INSERT_98625A950_MIN_MATERIAL,
    M3_CLEARANCE_DIAMETER,
    M3_NUT_ACROSS_FLATS,
    MAGNET_LENGTH,
    MAGNET_THICKNESS,
    MAGNET_WIDTH,
    SPRING_2006N292_FREE_LENGTH,
    SPRING_2006N292_OUTER_DIAMETER,
    SPRING_2006N292_WIRE_DIAMETER,
)
from schlieren.palette import (
    BRASS,
    METAL,
    PRINTED_AMBER,
    PRINTED_GRAY,
    PRINTED_GREEN,
    PRINTED_INDIGO,
    PRINTED_SKY,
    STEEL,
)
from schlieren.parts.adjuster import bearing_magnet, fas100_children, insert_98625a950
from schlieren.parts.rail_shoe import RailShoeParameters, post_stack
from schlieren.standards import (
    DATUM_DISC_THICKNESS,
    INCH,
    MAGNET_POCKET_CLEARANCE,
    NUT_POCKET_ACROSS_FLATS_CLEARANCE,
    OPTICAL_HEIGHT,
    PLA_MODULUS,
    POST_DIAMETER,
    POST_LENGTH,
)
from schlieren.validation import require_positive_dimensions
from schlieren.vendor_cad import SM1RC_M_THICKNESS


@dataclass(frozen=True)
class CarriageParameters:
    cassette_size: float = 64.0
    cassette_thickness: float = 5.0
    aperture_diameter: float = 24.0
    working_half_travel: float = 5.0
    loading_retraction: float = 6.0  # Additional motion from fiducial only.
    plate_width: float = 86.0
    plate_thickness: float = 4.0
    locator_diameter: float = 3.0
    locator_height: float = 0.8
    locator_diametral_clearance: float = 0.3
    locator_depth_clearance: float = 0.2
    # Post stack (§5) and Thorlabs SM1RC/M (vendor STEP model): Ø1.21 in bore accepting Ø1.20 in SM1 tubes.
    optical_height: float = OPTICAL_HEIGHT
    datum_thickness: float = DATUM_DISC_THICKNESS
    post_length: float = POST_LENGTH
    post_diameter: float = POST_DIAMETER
    ring_thickness: float = SM1RC_M_THICKNESS
    ring_bore: float = 1.21 * INCH
    # Rear spigot, same interface as the slit-head adapter (§7.6); printed at the SM1 tube nominal.
    spigot_diameter: float = 1.20 * INCH
    # Plate back to ring face, set by a shoulder on the spigot that the ring seats against. Longer than the
    # slit head's: the plate reaches below the rail-shoe top, so it must clear the shoe end, not just the post.
    ring_gap: float = 12.0
    spigot_shoulder_diameter: float = 34.0  # Bears on the SM1RC/M face outside its Ø30.7 mm bore.
    post_clearance: float = (
        2.0  # Minimum, plate back to post and rail shoe, and rotating parts to the rail top.
    )
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

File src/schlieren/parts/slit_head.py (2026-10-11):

"""Flexure source-slit head; canonical design §7 (selected baseline; first test print fits confirmed).

It replaces the §8 carriage and slit cassette for the source slit; the cutoff keeps the §8 carriage.
One flat-printed PLA flexure head carries both Stanley blades:

- frame -> platform: a parallelogram flexure for slit centering perpendicular to the slit, driven by
  FAS100 #1 (insert in the frame) against the coaxial 2006N292 spring, which supplies the preload;
- platform -> width stage: a nested parallelogram flexure carrying the movable blade, driven by FAS100 #2
  (insert in the platform) against the flexures' own preload.

Both parallelograms put their parasitic motion along the slit, where it is harmless. Stage rotation in the
slit plane (which would skew the slit, or open it in a taper) is controlled by keeping the drive forces off
the flexures: FAS100 #1 and the spring are coaxial and push on the platform's flexure connectors, so only
the small centering-flexure force is left unbalanced; the centering blades are spread to the top and bottom
of the platform; FAS100 #2 pushes on the width-stage connector. Rotation is estimated from a first-order
model (see `stage_rotation`), not FEA.

A separate flat printed adapter, spaced off the frame by M3 washers, carries a hollow SM1-tube-diameter
spigot that the SM1RC/M split ring clamps, so the head rotates continuously about the optical axis
(vertical, horizontal, and parallelism trim). Two identical printed clamp bars with EPDM faces pinch the
blades; no holes go through the blades.

Local frame, shown at rotation 0 (slit horizontal, knobs up): x along the slit, z the adjustment axis (+z
toward the knobs), y the optical axis, +y out of the head's front, the blade-seat side. The origin is the slit
center on the blade-seat plane (the carrier front faces). The head is modeled as printed: the platform at
mid travel and the width stage at zero flexure deflection.

Assembly frame is the §3.4 source rail frame, as light_source: x transverse, +y along the rail toward the
mirror, z=0 at the rail top, with the slit post at x=y=0. The head's front faces the light source (§7.2), so
local +y is rail -y and the spigot, ring, and post are on the mirror side of the blades (see head_location).
"""

from dataclasses import dataclass
from math import isfinite

from build123d import Axis, Pos, Rot, fillet

from schlieren.cad import (
    CUT_OVERRUN,
    assembly,
    box_between,
    compression_spring,
    labeled,
    y_cylinder,
    y_hex,
    z_cylinder,
)
from schlieren.hardware import (
    FAS100_PITCH,
    FAS100_THREAD_LENGTH,
    INSERT_98625A950_BODY_DIAMETER,
    INSERT_98625A950_FLANGE_DIAMETER,
    INSERT_98625A950_FLANGE_THICKNESS,
    INSERT_98625A950_LENGTH,
    INSERT_98625A950_MIN_MATERIAL,
    M3_CLEARANCE_DIAMETER,
    M3_NUT_ACROSS_FLATS,
    M3_NUT_THICKNESS,
    M3_SOCKET_HEAD_DIAMETER,
    M3_SOCKET_HEAD_HEIGHT,
    MAGNET_LENGTH,
    MAGNET_THICKNESS,
    MAGNET_WIDTH,
    SPRING_2006N292_FREE_LENGTH,
    SPRING_2006N292_OUTER_DIAMETER,
    SPRING_2006N292_WIRE_DIAMETER,
)
from schlieren.palette import (
    BRASS,
    METAL,
    PRINTED_BLUE,
    PRINTED_DENIM,
    RUBBER,
    STEEL,
)
from schlieren.parts.adjuster import bearing_magnet, fas100_children, insert_98625a950
from schlieren.parts.rail_shoe import post_stack
from schlieren.standards import (
    DATUM_DISC_THICKNESS,
    INCH,
    MAGNET_POCKET_CLEARANCE,
    NUT_POCKET_ACROSS_FLATS_CLEARANCE,
    OPTICAL_HEIGHT,
    PLA_MODULUS,
    POST_DIAMETER,
    POST_LENGTH,
)
from schlieren.vendor_cad import (
    SM1RC_M_THICKNESS,
    mcmaster_91292a114,
    mcmaster_91828a211,
)

LBF = 4.44822  # N


@dataclass(frozen=True)
class SlitHeadParameters:
    # Frozen project datum (§3.4) and post stack.
    optical_height: float = OPTICAL_HEIGHT
    datum_thickness: float = DATUM_DISC_THICKNESS
    post_length: float = POST_LENGTH
    post_diameter: float = POST_DIAMETER
    # Thorlabs SM1RC/M (vendor STEP model): Ø1.21 in bore accepting Ø1.20 in SM1 tubes.
    ring_thickness: float = SM1RC_M_THICKNESS
    ring_bore: float = 1.21 * INCH
    # Stanley 11-515 blades, measured (§7).
    blade_length: float = 38.99
    blade_width: float = 19.51
    blade_thickness: float = 0.254
    spine_thickness: float = 1.016
    spine_width: float = 2.0  # Display only; fold width not measured.
    slit_width: float = 0.20  # Display/setup value in the likely 0.15-0.20 mm working region.
    # Thorlabs FAS100 (drawing): 1/4"-80, 1.00 in thread from knob shoulder to ball tip.
    adjuster_thread_length: float = FAS100_THREAD_LENGTH
    adjuster_pitch: float = FAS100_PITCH
    adjuster_knob_diameter: float = 0.49 * INCH
    # McMaster 98625A950 brass insert (§8.3 drawing values).
    insert_bore: float = INSERT_98625A950_BODY_DIAMETER  # Print as pilot; finish with a 5/16 in drill.
    insert_length: float = INSERT_98625A950_LENGTH
    insert_min_material: float = INSERT_98625A950_MIN_MATERIAL
    insert_flange_diameter: float = INSERT_98625A950_FLANGE_DIAMETER
    insert_flange_thickness: float = INSERT_98625A950_FLANGE_THICKNESS
    # N52 10 x 5 x 2 mm magnet bearing pads under each FAS100 ball tip (§8.3).
    magnet_length: float = MAGNET_LENGTH
    magnet_width: float = MAGNET_WIDTH
    magnet_thickness: float = MAGNET_THICKNESS
    magnet_pocket_clearance: float = MAGNET_POCKET_CLEARANCE  # Total, across the magnet's length and width.
    # McMaster 2006N292 spring (§§8.4-8.5): free length and rate; 9 mm compression at mid travel.
    spring_free_length: float = SPRING_2006N292_FREE_LENGTH
    spring_mid_length: float = 16.5
    spring_rate: float = 0.14 * LBF  # N/mm
    spring_guide_pin_diameter: float = 3.6  # Inside the coil, which passes a 4 mm shoulder (§8.5).
    spring_guide_pin_length: float = 5.0
    spring_outer_diameter: float = SPRING_2006N292_OUTER_DIAMETER
    spring_wire_diameter: float = SPRING_2006N292_WIRE_DIAMETER
    spring_display_coils: float = 10.0  # Total turns of the displayed helix; approximate.
    spring_pocket_clearance: float = 1.0  # Diametral; printed-hole shrink and coil growth under compression.
    # Common M3 hardware: 91292A114 M3 x 12 SHCS, 91828A211 nut.
    screw_length: float = 12.0
    screw_clearance: float = M3_CLEARANCE_DIAMETER
    screw_head_diameter: float = M3_SOCKET_HEAD_DIAMETER
    screw_head_height: float = M3_SOCKET_HEAD_HEIGHT
    counterbore_clearance: float = 0.5  # Diametral.
    nut_across_flats: float = M3_NUT_ACROSS_FLATS
    nut_thickness: float = M3_NUT_THICKNESS
    nut_across_flats_clearance: float = NUT_POCKET_ACROSS_FLATS_CLEARANCE
    nut_axial_clearance: float = 0.3
    thread_protrusion: float = 0.5  # Screw tip beyond the far nut face.
    # McMaster 9852N37 EPDM on the clamp-bar faces, uncompressed.
    epdm_thickness: float = INCH / 32
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

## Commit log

2026-09-21 Initial rail shoe and tube clamp
2026-09-22 Adjust rail shoe post clearance
2026-09-22 Add carriage model
2026-09-30 Reorganize project for efficent Claude Code usage
    [bom.csv]
2026-10-01 Add /docs/reference; update LED module design
    [bom.csv]
2026-10-01 Project cleanup and LED module revisions
2026-10-02 Continue to evolve slit head and cutoff carriage
    [bom.csv]
2026-10-02 Cleanup and add heatsink model
2026-10-02 More document cleanup
    [bom.csv]
2026-10-03 CadQuery -> build123d, doc cleanups
    [bom.csv]
2026-10-03 Docs chapter reorg
    [bom.csv]
2026-10-03 Improve rail shoe render
2026-10-04 Combine LED and condenser to light source
    [bom.csv]
2026-10-04 Cleanup new light source section in docs
    [bom.csv]
2026-10-04 Add frame model
2026-10-05 Refine phone/lens mount
    [bom.csv, schlieren-bom.xlsx]
2026-10-05 Refine camera support
    [bom.csv, schlieren-bom.xlsx]
2026-10-05 Further refine camera support
    [bom.csv, schlieren-bom.xlsx]
2026-10-06 design doc and bom updates
    [bom.csv, schlieren-bom.xlsx]
2026-10-06 add light source drill/tap plan
    [bom.csv, schlieren-bom.xlsx]
2026-10-07 Add mirror cell model
    [bom.csv, schlieren-bom.xlsx]
2026-10-07 BOM xslx conversion enhancements
    [schlieren-bom.xlsx]
2026-10-08 Slit head no longer provisional
    [bom.csv, schlieren-bom.xlsx]
2026-10-08 Sub dowel pins for cut stainless rods
    [bom.csv, schlieren-bom.xlsx]
2026-10-08 doc updates
    [bom.csv, schlieren-bom.xlsx]
2026-10-09 model and doc updates, recent procurements
    [bom.csv, schlieren-bom.xlsx]
2026-10-09 rename 'lens pointer' to 'lens cradle'
    [bom.csv, schlieren-bom.xlsx]
2026-10-10 Add entire optics head assembly
2026-10-10 Invert bearing in cutoff carriage
    [carriage.py]
2026-10-11 Remove parts/README, DRY magnet pockets
2026-10-11 Stricter ruff and lint fixes
    [carriage.py]
2026-10-11 ChatGTP code review fixes
    [schlieren-bom.xlsx]
2026-10-11 Carriage updates
2026-10-11 Add carriage stack hardware and datum brads to model
2026-10-11 Further carriage tweaks
2026-10-11 Tighten up AGENTS.MD
2026-10-11 Remove 'mock-up' language from lens cradle
2026-10-11 Increase phone model fidelity. Remove carriage plate locator tabs/sockets.
2026-10-12 Higher fidelity telephoto lens model
2026-10-12 Cutoff carriage verified
2026-10-12 BOM updates; add locating ridge for lens collar lateral stop pins
2026-10-13 Add rail hardware to phone rest; cleanup light source docs
2026-10-13 Add hardware models for LED module model, correct BOM lint
2026-10-14 Rail mount hardware clarification
2026-10-14 BOM note cleanups
2026-10-14 Add spot drill bits to bom; re-render figures and doc
2026-10-15 Refine phone and case models
2026-10-16 render rail hardware in camera support
2026-10-17 Lighten telephoto lens barrel color for contrast
2026-10-17 BOM and provisional task updates
2026-10-17 Update notes on heat set installation tooling
2026-10-18 Light source drilling plan updates
2026-10-18 Update remaining work lens cradle / phone support
2026-10-19 more fidelity in phone and case models
2026-10-21 BOM updates
2026-10-23 Add LED hole drilling fixture
2026-10-24 update led drill fixtures
2026-10-26 Update heatsink drill nest
2026-10-26 Adjust heatsink drill cage
2026-10-26 Adjust drill fixture bores after test fits with coupon
2026-10-27 more doc cleanup on layout and frame
2026-10-27 Doc cleanup: frame and post support
2026-10-27 Add bores to led mounting cap and heatsink models
2026-10-28 Update after drill fixture build
2026-10-29 Higher fidelity razor blades; ground glass focus screen
2026-11-07 Add omitted PTFE shim stock to BOM
2026-11-10 Add field lens to light source
2026-11-11 BOM update
2026-11-14 BOM and reference updates
